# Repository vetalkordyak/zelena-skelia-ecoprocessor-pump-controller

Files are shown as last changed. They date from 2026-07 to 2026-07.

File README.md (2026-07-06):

# Zelena Skelia EcoProcessor — Pump Controller (ESPHome)



> ⚠️ Non-commercial, unofficial "as is" project — no warranty, no
> liability on the author's part for any consequences of use. Details:
> section "8. License and Disclaimer" below.

*(Українську версію цього README дивіться в [`README_uk.md`](./README_uk.md).)*

A circulation-pump controller for a biofilter, based on ESP8266 (Wemos
D1 mini), with smooth pulsed power control via an AC dimmer (leading-edge
phase-cut). This firmware is a copy / analog of the **EcoProcessor**
controller firmware and is fully compatible in principle of operation
with **«Zelena Skelia»** biological septic systems — the same cyclic
irrigation algorithm (ramp up → run → ramp down → rest), multi-stage
pump overload protection, and automatic restart after a fault.

---

## Why this controller is needed

> 📺 **Source.** The description of the EcoProcessor's principle of
> operation and its programs (P1/P2/P3, irrigation cycles, energy
> savings) was obtained from an open source — an official video on the
> «Zelena Skelia» YouTube channel:
> https://www.youtube.com/watch?v=CfAyo-JgoCA

### The «Air Ring»® / «Eco Ring» biofilter

Plastic discs **«Air Ring»®** (or **«Eco Ring»**) are the most important
element of a standalone-sewage biofilter. Made of rigid plastic, with a
usable loading surface area of **180 m² per 1 m³**.

- **Biofilm formation.** The discs' main job is to provide an optimal
  environment for beneficial bacteria — naturally present in wastewater —
  to attach and develop. Microorganisms fix themselves onto the plastic
  surface, forming a biofilm, and feed on organic contaminants in the
  wastewater, oxidizing and breaking them down.
- **Self-cleaning ability.** The discs have a unique ability to clean
  themselves of dead biofilm residue. In older generations of filters,
  it was precisely dead bacteria that caused rapid clogging of the media,
  worsened aeration, and putrefaction, which would completely stop the
  treatment process. «Air Ring»® / «Eco Ring» discs require no special
  cleaning or replacement — they are durable and do not degrade during
  operation.
- **Advantages over brush and honeycomb media:** efficiency (greater
  contact between air, water, and microorganisms), environmental
  friendliness (no fine particles released into water or soil),
  cost-effectiveness (allows air flow to be dispersed at lower pressure
  without compressors that must run continuously), practicality
  (successfully tested in over 40,000 biofilters in more than 30
  countries worldwide — from hot climates to the Arctic).

### The role of the circulation pump

1. **Intake of clarified water.** First, domestic wastewater undergoes
   thorough mechanical treatment to remove fats, insoluble matter, and
   solid debris across three sections of the septic tank.
2. **Lifting and irrigation (aeration).** The pump lifts the already
   pre-clarified water up into the biological reactor. There, it
   irrigates (sprays) the liquid over the «Air Ring»® discs several
   times. This saturates the water with oxygen and brings it into active
   contact with the biofilm on the discs, where bacteria complete the
   biological breakdown of organic matter.

Reliable pump equipment from well-known global brands is used for
this — namely **Wilo, Kärcher, or Grundfos**.

> ⚙️ **Max Power and Min Power must be calibrated manually for each
> specific septic tank.** There is no one-size-fits-all setting —
> nozzles/sprayers, lift height, and the number of «Air Ring»® discs
> differ from installation to installation. So after mounting, these two
> parameters need to be **set empirically**, by observing the actual
> irrigation inside the bioreactor: the liquid must **evenly cover and
> irrigate all the discs**, without dry spots (too little power — doesn't
> reach/cover everything) and without overshoot or spraying past the
> media (too much power). Ramp Up/Down then smoothly "swings" the flow
> between these two verified limits, rather than between arbitrary
> values.

### The role of the controller

Thanks to the intelligent **EcoProcessor** control unit, the pump is
protected from overloads through a **multi-stage protection** system.
In addition, the controller optimizes the pump's operating cycles,
reducing the system's overall energy consumption by **more than 10x**.
For example, a Wilo-brand pump in such a system consumes only **33 W of
electricity per hour**.

This ESPHome firmware implements the same idea in an open way:

- **Cyclic irrigation instead of continuous operation** (P1/P2 modes,
  run ⇄ rest) — exactly the cycle optimization that delivers the
  multi-fold energy savings.
- **Smooth phase-cut power ramp up/down** (Ramp Up/Down) instead of a
  sudden full-power switch-on — a gentler start and stop on every
  irrigation cycle, less strain on the pump.
- **Pump current monitoring and automatic restart** — the controller
  watches the current and reacts to abnormal operating conditions
  (overload, rotor jam) by shutting the pump off and trying to restart
  it after a pause; the owner sees the retry counter (`Restart Attempts`)
  in the web UI.

---

## 1. Components

| # | Component | Purpose | Purchase link |
|---|---|---|---|
| 1 | **Wemos D1 mini V4 (ESP8266)** | microcontroller, Wi-Fi, web UI | https://www.aliexpress.com/item/32831353752.html |
| 2 | **AC Dimmer RobotDyn (1-channel)** | leading-edge phase-cut for smooth pump power control | https://www.aliexpress.com/item/32802025086.html |
| 3 | **ACS712 5A current sensor** *(inferred from the 0.185 V/A coefficient in the code — the standard sensitivity of the ACS712-5A, 185 mV/A)* | measures pump current for status indication and fault detection (power terminals IP+/IP− — on the dimmer's output, before the pump) | https://www.aliexpress.com/item/1005008375334741.html |
| 4 | **HLK-5M05 power supply**, isolated AC-DC 220V→5V | powers the Wemos D1 mini and the ACS712's logic side | https://www.aliexpress.com/item/1005009246796870.html |
| 5 | Drainage/circulation pump (AC, single-phase, ~220V) | actuator | depends on the installation, not included |

---

## 2. Wiring diagram (ASCII)

### 2.1 220V power circuit (mains → dimmer → current sensor → pump)

The ACS712 sits **on the dimmer's output** (after the phase cut), in
series with the phase conductor between the dimmer and the pump — i.e.
it measures exactly the current actually going to the pump, not the
overall mains current upstream of the dimmer.

```
  ~220V AC MAINS
   L ●───────────────────────────────────────┐
   N ●───────────────────┐                   │
                          │                   │
                          ▼                   ▼
              ┌─────────────────────────────────────────┐
              │            AC Dimmer RobotDyn             │
              │                                           │
              │   AC-IN(N)                    AC-IN(L)    │
              │                                           │
              │            (triac, phase-cut)             │
              │                                           │
              │   AC-OUT(N)                  AC-OUT(L)    │
              └───────┬───────────────────────────┬───────┘
                      │                            │
                 GATE ●│                  Z-CROSS ●│   ── signals to ESP8266 (see 2.2)
                      │                            │
                      │                            ▼
                      │                  ┌───────────────────┐
                      │                  │     ACS712-5A       │
                      │                  │   IP+ ────── IP−    │  ── current sensor,
                      │                  └──────┬───────┬──────┘     IN SERIES WITH L,
                      │                     OUT │(analog)             AFTER the dimmer
                      │                         │       │
                      ▼                         │       ▼
              ┌───────────────────────────────────────────┐
              │                  PUMP                       │
              │            N                    L           │
              └───────────────────────────────────────────┘
```

### 2.2 Control signals → Wemos D1 mini (ESP8266)

```
  GATE (from dimmer)     ───────────►  GPIO4 (D2)
  Z-CROSS (from dimmer)  ◄───────────  GPIO5 (D1)
  ACS712 OUT (analog)    ───────────►  A0
  LED indicator          ◄───────────  GPIO2 (D4, active LOW)
```

### 2.3 Logic power supply (220V → 5V, isolated)

The HLK-5M05 supplies 5V/GND to **two** consumers at once: the Wemos D1
mini (via the VBUS/5V pin) and the ACS712's logic side (the module's own
VCC/GND pins — not to be confused with the IP+/IP− power terminals,
which sit separately in series with L, see 2.1):

```
                               ┌──► 5V/GND ──► Wemos D1 mini (VBUS, GND)
~220V AC MAINS ──► HLK-5M05 ──┤
   (AC-DC, isolated)           └──► 5V/GND ──► ACS712 (VCC, GND — logic side)
```

**ESP8266 pin map (per the `pump_controller.yaml` code):**

| Wemos pin | Function | Connects to |
|---|---|---|
| `GPIO4` (D2) | dimmer `gate_pin` | DIM on the AC Dimmer RobotDyn |
| `GPIO5` (D1) | `zero_cross_pin` (input) | Z-C on the AC Dimmer RobotDyn |
| `GPIO2` (D4) | LED output (inverted — active LOW) | status LED |
| `A0` | ADC analog input | ACS712 current sensor OUT (logic side) |
| `3V3` | dimmer logic power | VCC on the AC Dimmer RobotDyn |
| `5V`, `GND` (VBUS) | power | HLK-5M05 output (shared with ACS712's VCC/GND) |

> ⚠️ **Electric shock hazard.** The AC Dimmer, ACS712 (in series with the
> phase), and HLK-5M05 operate at mains voltage (220V). All wiring work
> must only be done with the panel/line fully de-energized, ideally
> through a breaker and RCD. The Wemos D1 mini's logic side (GPIO/A0/5V)
> is galvanically isolated from the mains only thanks to the isolated
> HLK-5M05 power supply — do not use non-isolated power supplies.

---

## 3. Principle of operation

The firmware implements a non-blocking state machine (`interval:` every
100ms) with four states:

```
      0 = stopped
        │ (Pump: Enabled = ON)
        ▼
      1 = running ──(work phase reached Work Time)──► 2 = resting
        ▲                                                  │
        │◄────────────────(Rest Time elapsed)──────────────┘
        │
        │ (fault: no current while the dimmer is active)
        ▼
      3 = fault ──(Retry Delay elapsed)──► back to 1 = running
```

### Operating modes (`select: Operating Mode`)

Switched via a single selector in the web UI ("Pump Control" group),
no reflashing needed. Changing the mode on the fly immediately starts a
new cycle from the "running" phase (`g_state = 1`, ramp up).

#### P1 Standard — normal operating mode

- Work: **120s (2 min)**, rest: **480s (8 min)** → full cycle 10 min,
  the pump is active ≈ **20%** of the time.
- Use case: typical daily load — wastewater comes in regularly, requires
  regular circulation/discharge without excessive pump wear.
- All 4 timing parameters (Work/Rest/Ramp Up/Ramp Down Time) are
  editable separately in the "Mode P1 — Standard" group.

#### P2 Economy — economy mode

- Work: **60s (1 min)**, rest: **1740s (29 min)** → full cycle 30 min,
  the pump is active only ≈ **3.3%** of the time.
- Use case: periods of low load (night, no occupants, off-season) —
  significantly less pump run-time and power consumption, while the
  liquid still doesn't stagnate.
- Parameters are fully independent from P1 (separate "Mode P2 —
  Economy" group) — both profiles can be kept ready and switched
  between without recalculating anything.

#### P3 Constant — pump testing mode

- The pump runs at **100% power continuously**, with no "run/rest"
  cycling and no level pulsing at all — ramps (Ramp Up/Down) are not
  used here, the dimmer is effectively fully open.
- Use case: **exclusively for testing the pump at full power without
  the dimmer** — to check whether the pump itself is functional and
  draws normal current/flow, without any influence from phase control.
  This is not a normal operating mode for the biofilter.
- Fault detection still works here too, but via a separate code branch:
  it checks directly whether there is current at 100% power, with no
  dependency on the ramp up/down phase (which doesn't exist in this
  mode).

#### Power pulsing within the "run" phase (P1/P2)

Unlike simply "switch on at a fixed power," in P1/P2 modes the power
level within the run phase continuously **pulses in a triangle wave**
between **Min Power** and **Max Power** until the work time ends:

```
level (%)
 Max ─┤      ╱╲          ╱╲          ╱╲
      │     ╱  ╲        ╱  ╲        ╱  ╲
      │    ╱    ╲      ╱    ╲      ╱    ╲
 Min ─┤   ╱      ╲    ╱      ╲    ╱      ╲
      └──┴────────┴──┴────────┴──┴────────┴──► time
         Ramp Up  Ramp Down  Ramp Up  Ramp Down …
         (e.g. 0.1s)  (e.g. 14s)
```

In other words, one "tooth" = Ramp Up Time (fast rise to Max) + Ramp
Down Time (slower decay to Min), repeating in a loop until the run phase
ends. By default the ramp-up is much faster than the ramp-down (0.1s vs
14s) — an almost instant "kick" followed by a smooth fade, rather than a
symmetric sine wave. This is the same "smooth pulsing" mentioned at the
top of this README — it's gentler on the pump and pipes than holding one
fixed power level for the entire run phase.

#### Example factory settings (from the video)

In the official «Zelena Skelia» video (source — see the top of this
README), the manufacturer gives an example configuration of the
EcoProcessor control unit for three septic tank models. The original
notation (as spoken in the video) and its decoding into this firmware's
terms are shown side by side, for verification:

**Video notation:** `H` = Rest (minutes), `H.` = Work (minutes),
`h` = Ramp Down (seconds), `h.` = Ramp Up (seconds), `V` = Min Power (%),
`V.` = Max Power (%).

| Model | Mode | Original from the video | Work Time | Rest Time | Ramp Up | Ramp Down | Min Power | Max Power |
|---|---|---|---|---|---|---|---|---|
| **ZS4** | P1 (Р-1) | `H8 H.2 \ h14 h.1 \ V32 V.38` | 120s (2 min) | 480s (8 min) | 0.1s | 14s | 32% | 38% |
| **ZS4** | P2 (Р-2) | `H29 H.1 \ h14 h.1 \ V32 V.38` | 60s (1 min) | 1740s (29 min) | 0.1s | 14s | 32% | 38% |
| **ZS6** *(3 turns)* | P1 (Р-1) | `H13 H.2 \ h14 h.1 \ V37 V.55` | 120s (2 min) | 780s (13 min) | 0.1s | 14s | 37% | 55% |
| **ZS6** | P2 (Р-2) | `H29 H.1 \ h14 h.1 \ V37 V.55` | 60s (1 min) | 1740s (29 min) | 0.1s | 14s | 37% | 55% |
| **ZS8** | P1 (Р-1) | `H10 H.2 \ h14 h.1 \ V37 V.55` | 120s (2 min) | 600s (10 min) | 0.1s | 14s | 37% | 55% |
| **ZS8** | P2 (Р-2) | `H29 H.1 \ h14 h.1 \ V37 V.55` | 60s (1 min) | 1740s (29 min) | 0.1s | 14s | 37% | 55% |

Work Time, Rest Time, Ramp Up, and Ramp Down in this firmware's defaults
already match the **ZS4** row in the table above (120s/480s for P1,
60s/1740s for P2, 0.1s/14s ramp up/down). **The default Max Power and
Min Power (75%/55%) do not match the video** — this is either a
different model, or values manually tuned for a specific pump (see the
⚙️ note above about calibrating Max/Min Power for actual disc
irrigation).

### Fault protection

If the dimmer is active (`level ≥ 5%`) and the current sensor (`ACS712`)
sees no current for more than **Fault: Detection Time** seconds — the
system treats this as a fault (overload / rotor jam), shuts the pump
off, waits **Fault: Retry Delay** seconds, and tries to start again. The
retry counter (`Restart Attempts`) is visible in the web UI. This
function can be disabled via the **Fault Detection: Enabled** switch.

### Current measurement (RMS)

Because of the dimmer's phase-cut, the pump current is not a smooth sine
wave but a series of short pulses. `Pump Current` is therefore computed
as a true RMS over ~200 direct ADC samples across ~40ms (≈2 mains
cycles), rather than a single "instantaneous" snapshot — this eliminates
the reading jumps typical of naive single-sample measurement under
phase control.

### LED indication (LED, GPIO2)

A single onboard LED shows the system's current state without needing
to open the web UI. The "tick" logic (`g_led_tick`) generates a cycle of
20 ticks at 100ms each = **2 seconds per full pattern cycle**, and all
the patterns below are built on that cycle length.

| State | What the LED shows | Pattern (1 cell = 100ms, 2s total) |
|---|---|---|
| **0 — Stopped** | Off continuously | `░░░░░░░░░░░░░░░░░░░░` |
| **1 — Running** | Solid on (no blinking) | `████████████████████` |
| **2 — Resting** | 1 short blink every 2s (100ms on / 1900ms off) | `█░░░░░░░░░░░░░░░░░░░` |
| **3 — Fault** | Double blink every 2s (2×200ms on with a gap, then a long pause) | `██░░██░░░░░░░░░░░░░░` |

*(`█` = LED on, `░` = off; read left to right as 20 consecutive 100ms
segments)*

So, just by looking at the indicator, you can tell the state at a
glance:
- **not blinking, not lit** → pump stopped (Pump: Enabled = OFF, or P3
  hasn't started yet);
- **solidly lit, no blinking** → currently in the "running" phase;
- **one short "blip" every ~2s** → the "rest" phase between cycles
  (Resting) — everything is normal, just waiting;
- **two short blinks in a row every ~2s** → fault, the system is
  waiting before retrying — worth checking the pump/pipe if this
  repeats (see the `Restart Attempts` counter).

> Note: in **P3 Constant** mode, the LED behaves as in the Running
> state (solid on) until a fault occurs — there is no separate pattern
> for P3, since for the controller it's just another kind of "running."

---

## 4. Web interface (`web_server`, port 80)

Settings are grouped on the device's page:

| Group | Contains |
|---|---|
| **Pump Control** | operating mode (P1/P2/P3), pump on/off |
| **Power Settings** | Max Power / Min Power (%) — shared between P1 and P2, calibrated empirically for the specific septic tank (see "The role of the circulation pump" above) |
| **Status & Monitoring** | current phase, time remaining (M:SS), power, current, running status |
| **Mode P1 — Standard** | work/rest/ramp-up/ramp-down time + a text minute-hint under each parameter |
| **Mode P2 — Economy** | the same for the economy mode |
| **Fault & Recovery** | fault detection time, retry delay, retry counter |

---

## 5. Installation / flashing

1. Install ESPHome:
   ```bash
   pip install esphome
   ```
2. Open `pump_controller.yaml` and replace the placeholders with your
   actual values (Wi-Fi, API key, OTA password, fallback AP password):

   | Placeholder in the file | What to substitute |
   |---------------------------|-----------------------|
   | `YOUR_WIFI_SSID` / `YOUR_WIFI_PASSWORD` | your main Wi-Fi network |
   | `YOUR_WIFI_SSID_2` / `YOUR_WIFI_PASSWORD_2` | backup Wi-Fi network |
   | `YOUR_API_ENCRYPTION_KEY_BASE64` | Home Assistant API encryption key — generate with: `python3 -c "import base64,os; print(base64.b64encode(os.urandom(32)).decode())"` |
   | `YOUR_OTA_PASSWORD` | your own OTA update password |
   | `YOUR_AP_FALLBACK_PASSWORD` | fallback Access Point password (appears if Wi-Fi is unavailable) |

   > The file is self-contained — no separate `secrets.yaml` is needed,
   > but for that exact reason **do not publish it publicly once you've
   > filled in real values** (it then contains real passwords/keys, not
   > placeholders).
3. First flash — via USB (requires a cable to the Wemos D1 mini):
   ```bash
   esphome run pump_controller.yaml
   ```
4. All subsequent updates — over the network (OTA), no cable needed:
   ```bash
   esphome upload pump_controller.yaml
   ```
5. Device web UI: `http://<device-ip>/` (the config defaults to a
   static address of `192.168.5.123` — change `use_address` under
   `wifi:` if needed).

---

## 6. Safety

- Once you've filled in the placeholders with real Wi-Fi passwords, an
  API key, and an OTA password, **do not publish or commit this
  `pump_controller.yaml` to a public git repo/cloud** — unlike the
  placeholder template, the filled-in file now contains real secrets.
- All 220V wiring work must be done only by a qualified professional
  with the power off, through a circuit breaker and RCD.

---

## 7. Enclosure (3D printing)

The [`3d-print/`](./3d-print/) folder contains an example enclosure for
3D printing:

| File | Purpose |
|---|---|
| `enclosure-top.stl` | top part of the enclosure |
| `enclosure-bottom.stl` | bottom part of the enclosure |
| `enclosure-latch.stl` | latch/fastener |

> ⚠️ This is a **working "as is" example**, not a refined engineering
> model. The components inside (Wemos, dimmer, ACS712, HLK) were
> attached with hot glue, without precise dimensioning of the mounting
> points — so the enclosure will likely need rework for your specific
> set of components. If you have 3D-design skills, feel free to improve
> the mounts, ventilation, cable entries, etc., and make it better.

---

## 8. License and Disclaimer

**License:** the code in this project (`pump_controller.yaml`) is
distributed under the **MIT License** — see the [`LICENSE`](./LICENSE)
file. You are free to use, copy, modify, and distribute it, with no
warranty.

**Non-commercial, unofficial project.** This is a hobbyist project
built for personal home use. The project is **not affiliated or
associated** with the «EcoProcessor» manufacturer, the **«Zelena
Skelia»** brand, the owners of the «Air Ring»® / «Eco Ring» trademarks,
or the pump manufacturers (Wilo, Kärcher, Grundfos), and is not their
official or licensed firmware or product. All mentioned names are the
property of their respective rights holders, referenced here solely to
explain compatibility and the principle of operation.

**Patents and underlying technology.** The original systems mentioned
in this README (biofilters, pump control algorithms, etc.) may be
protected by patents or other intellectual property rights of their
manufacturers. The description of the EcoProcessor's principle of
operation and its programs in this README is based solely on an **open
source** — an official video on the «Zelena Skelia» YouTube channel
(https://www.youtube.com/watch?v=CfAyo-JgoCA), without access to any
internal/proprietary manufacturer documentation. This project makes no
claim to rights over such technology — the implementation in
`pump_controller.yaml` is an independent, self-made development by the
author for their own equipment.

**Disclaimer.** The firmware and documentation are provided **"AS IS"**,
without any warranty. You install and use this controller **entirely at
your own risk**. The work involves wiring under mains voltage (220V —
electric shock hazard) and controlling the pump of a wastewater
treatment system (risk of equipment damage, overflow, or septic system
failure from incorrect configuration or malfunction). The author
**bears no liability** for any damages, injuries, property damage,
failure of the biological treatment process, or other consequences,
direct or indirect, related to using, assembling, or modifying this
project. Installing the 220V power section is recommended to be
entrusted to a qualified electrician.

---

## 9. Project files

| File | Purpose |
|---|---|
| `pump_controller.yaml` | main ESPHome configuration, English (comments + web UI text), with placeholders instead of secrets |
| `pump_controller_uk.yaml` | the same configuration, in Ukrainian |
| `3d-print/enclosure-top.stl` | top part of the enclosure (3D printing) |
| `3d-print/enclosure-bottom.stl` | bottom part of the enclosure (3D printing) |
| `3d-print/enclosure-latch.stl` | enclosure latch/fastener (3D printing) |
| `LICENSE` | MIT license text |
| `README.md` | this file (English) |
| `README_uk.md` | Ukrainian version of this README |

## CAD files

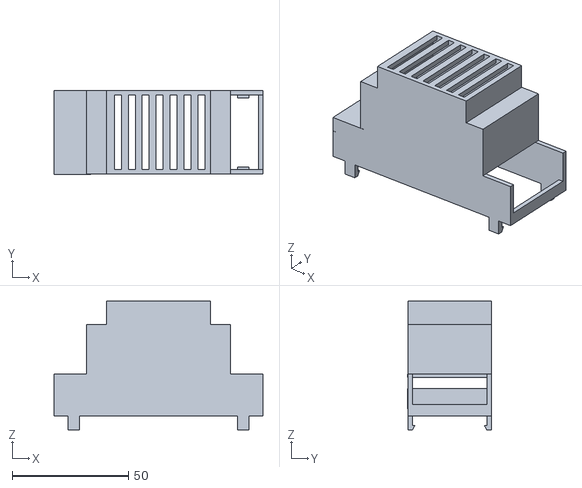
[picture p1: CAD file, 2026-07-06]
3d-print/enclosure-top.stl
90.0 x 36.1 x 55.5

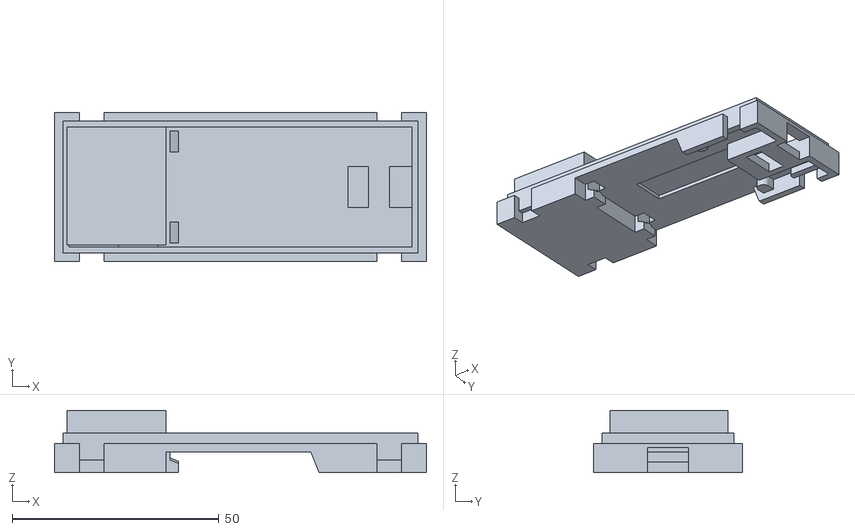
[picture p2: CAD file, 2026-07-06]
3d-print/enclosure-bottom.stl
90.0 x 36.0 x 15.0

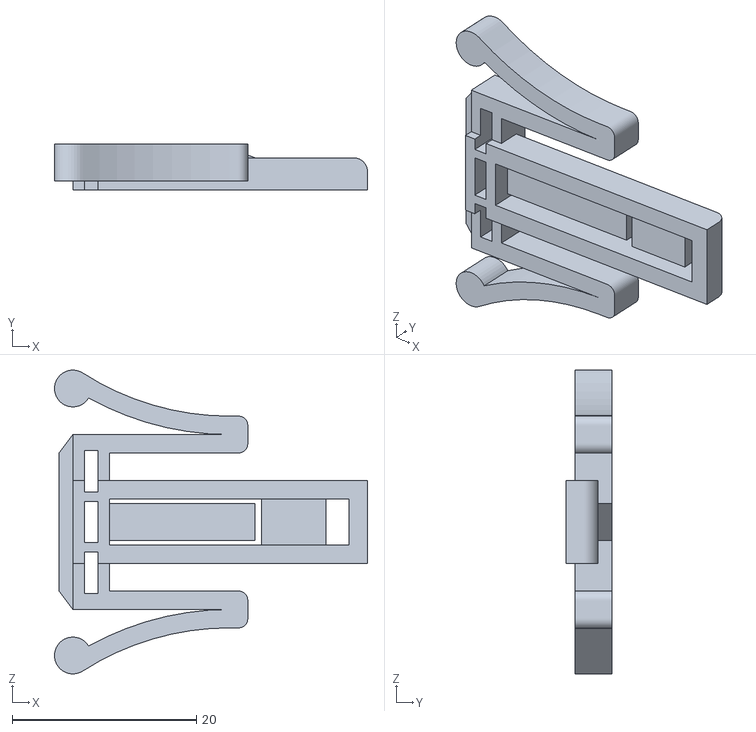
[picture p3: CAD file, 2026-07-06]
3d-print/enclosure-latch.stl
34.0 x 5.00 x 33.0

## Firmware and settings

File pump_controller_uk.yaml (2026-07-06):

esphome:
  name: pump-controller
  friendly_name: "Drainage Pump"
  on_boot:
    priority: -100   # після ініціалізації всіх компонентів
    then:
      - delay: 1s    # дати ADC стабілізуватись
      - component.update: adc_raw
      - lambda: |-
          float v = id(adc_raw).state;
          if (id(adc_raw).has_state() && !isnan(v)) {
            id(g_adc_idle) = v;
          }

esp8266:
  board: d1_mini

logger:
  level: INFO

api:
  encryption:
    key: "YOUR_API_ENCRYPTION_KEY_BASE64"   # generate: python3 -c "import base64,os; print(base64.b64encode(os.urandom(32)).decode())"

ota:
  - platform: esphome
    password: "YOUR_OTA_PASSWORD"

wifi:
  networks:
    - ssid: "YOUR_WIFI_SSID"
      password: "YOUR_WIFI_PASSWORD"
    - ssid: "YOUR_WIFI_SSID_2"
      password: "YOUR_WIFI_PASSWORD_2"
  ap:
    ssid: "PumpCtrl Fallback"
    password: "YOUR_AP_FALLBACK_PASSWORD"

  use_address: 192.168.5.123

captive_portal:

# ================================================================
# WEB SERVER: версія 3 з групуванням параметрів
# ================================================================
web_server:
  port: 80
  version: 3
  sorting_groups:
    - id: group_control
      name: "Pump Control"
      sorting_weight: 1
    - id: group_power
      name: "Power Settings"
      sorting_weight: 2
    - id: group_status
      name: "Status & Monitoring"
      sorting_weight: 3
    - id: group_p1
      name: "Mode P1 — Standard"
      sorting_weight: 4
    - id: group_p2
      name: "Mode P2 — Economy"
      sorting_weight: 5
    - id: group_fault
      name: "Fault & Recovery"
      sorting_weight: 6

# ================================================================
# OUTPUT: AC Dimmer RobotDyn
# gate_pin   = GPIO4 (D2)
# zero_cross = GPIO5 (D1)
# ================================================================
output:
  - platform: gpio
    id: led_output
    pin:
      number: GPIO2
      inverted: true  # Wemos D1 Mini: LED is active LOW

  - platform: ac_dimmer
    id: dimmer_output
    gate_pin: GPIO4
    zero_cross_pin:
      number: GPIO5
      mode:
        input: true
    min_power: 0.0
    method: leading_pulse

# ================================================================
# GLOBALS: Змінні стану (не зберігаються у flash)
# ================================================================
globals:
  - id: g_state       # 0=stopped  1=running  2=resting  3=fault
    type: int
    restore_value: false
    initial_value: '0'

  - id: g_phase_ms
    type: uint32_t
    restore_value: false
    initial_value: '0'

  - id: g_pulse_ms
    type: uint32_t
    restore_value: false
    initial_value: '0'

  - id: g_ramp_up     # true=ramp up, false=ramp down
    type: bool
    restore_value: false
    initial_value: 'true'

  - id: g_level       # поточний рівень димера [0.0…1.0]
    type: float
    restore_value: false
    initial_value: '0.0'

  - id: g_adc_idle    # базова напруга АЦП у стані спокою [В]
    type: float
    restore_value: false
    initial_value: '2.5'

  - id: g_fault_ms    # millis() початку аварії (0 = немає)
    type: uint32_t
    restore_value: false
    initial_value: '0'

  - id: g_retry_count # лічильник спроб перезапуску
    type: int
    restore_value: false
    initial_value: '0'

  - id: g_led_tick    # лічильник тіків для LED-патернів (0…19, цикл 2 с)
    type: uint8_t
    restore_value: false
    initial_value: '0'

  - id: g_fault_enabled  # стан "Fault Detection" — зберігається у flash
    type: bool
    restore_value: true
    initial_value: 'true'

# ================================================================
# SELECT: Вибір режиму роботи
# ================================================================
select:
  - platform: template
    name: "Operating Mode"
    id: pump_mode
    optimistic: true
    restore_value: true
    options:
      - "P1 Standard"
      - "P2 Economy"
      - "P3 Constant"
    initial_option: "P1 Standard"
    web_server:
      sorting_group_id: group_control
      sorting_weight: 10
    on_value:
      then:
        - lambda: |-
            if (id(g_state) != 0) {
              uint32_t now = millis();
              id(g_state)    = 1;
              id(g_phase_ms) = now;
              id(g_pulse_ms) = now;
              id(g_ramp_up)  = true;
              id(g_fault_ms) = 0;
            }
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

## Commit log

2026-07-06 Initial commit: Zelena Skelia EcoProcessor pump controller (ESPHome)
    Non-blocking state-machine firmware for a biofilter circulation pump,
    with pulsed phase-cut power control, current-based fault detection,
    web UI, and an example 3D-printable enclosure.
    [enclosure-bottom.stl, enclosure-latch.stl, enclosure-top.stl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]
2026-07-06 Add Ukrainian firmware variant (pump_controller_uk.yaml)
    pump_controller.yaml is now fully English (comments + web UI text and
    descriptions). pump_controller_uk.yaml keeps the original Ukrainian
    comments and UI text. Both READMEs updated to reference the matching
    language variant and list both files.
    [pump_controller_uk.yaml]
